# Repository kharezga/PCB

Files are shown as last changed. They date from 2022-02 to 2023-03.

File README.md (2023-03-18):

# My PCBs
This repository contains sereveral PCB board that I've design for use in the Formula Student racecar. In addition to PCB designs, the repository also includes 3D models of some of their housings.

## 🚨 Tractive System Active Light (TSAL) module 🚨
According to the Formula Student Rules 2022, the Tractive System Active Light (TSAL) is a safety feature that must be implemented in all electric vehicles participating in the competition. Whole project of the TSAL can be found in this repository, including PCB layout and scheme. 

### Overview
The TSAL must be based on the voltage level of the High Voltage (HV) battery or the voltage level of the motor controller, and it should indicate whether the tractive system is active or not.

The TSAL should be mounted on the rear of the vehicle and must be clearly visible from the rear of the vehicle during both day and night conditions. The light should be red or yellow and must flash at a frequency between 1Hz and 4Hz.

During normal operation, the TSAL should remain on steadily to indicate that the tractive system is active. When the vehicle is in an emergency or shutdown state, the TSAL should flash at a higher frequency between 4Hz and 10Hz to indicate that the tractive system is inactive.

## Ready-to-Run Sound and Autonomous System Status Indicators module
In this repository there is also a project containing a module for ready-to-run-sound and ASSI safety systems.

### 🔊 Ready-to-Run Sound 🔊
According to the Formula Student Rules 2022, Ready-to-Run Sound (RtRS) is a safety feature that must be implemented in all electric vehicles participating in the competition.

The purpose of the RtRS is to alert pedestrians and other drivers of the presence of an electric vehicle, which can be difficult to hear due to its quiet operation. The sound must be continuous, with a minimum sound pressure level of 55dB(A) and a maximum of 75dB(A) measured at a distance of 2 meters from the vehicle in all directions.

The RtRS must be activated when the vehicle is in Ready-to-Run mode, which means the vehicle is ready to move and all systems are operational. The sound should be automatically turned off when the vehicle is not in Ready-to-Run mode or is turned off.

### 🤖 Autonomous System Status Indicators 🤖
According to the Formula Student Rules 2022, the Autonomous System Status Indicators (ASSI) module is a safety feature that must be implemented in all autonomous vehicles participating in the competition.

The ASSI module is responsible for providing visual and audible feedback on the status of the autonomous system to the vehicle occupants, other drivers, and pedestrians. The module must be integrated into the vehicle's user interface or dashboard and should display the following information:

+ Autonomous System Status: The module must display the status of the autonomous system, indicating whether it is active or inactive.
+ System Health Status: The module must display the health status of the autonomous system, indicating whether the system is functioning correctly or not.
+ System State: The module must display the current state of the autonomous system, indicating whether the system is in calibration mode, initialization mode, or autonomous driving mode.

In addition to the visual feedback, the ASSI module must also provide audible feedback to alert the vehicle occupants and pedestrians of any critical issues related to the autonomous system. The audible feedback must be distinct and easily identifiable from any other sounds in the vehicle or surrounding environment.

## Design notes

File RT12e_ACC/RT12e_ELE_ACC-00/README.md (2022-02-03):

# RT12e_ELE_ACC_00
Projekt w kiCad'ie 5.1.8
Całość jest takze w pdf'ie w docs.

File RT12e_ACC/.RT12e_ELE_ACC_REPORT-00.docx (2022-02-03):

ELECTRONICS HARDWARE REPORT

Part | Rt12e_ELE_ACC
Department | Electronics
Owner | Bartosz Gwiazda
Owner’s e-mail | bartosz.gwiazda.pwrrt@gmail.com
Owner’s phone no. | 505613201
Season | 2020/21
Car | RT12e

# 1. Rules defining the part

# 2. Schedule

Beginning | End | Task
5.11 | 13.11 | Scheme creation
13.11 | 25.11 | Layout creation
11.12 | 18.12 | Fixes
4.01 | 12.01 | Case model

# 3. Description and ASSUmPTIONS of the part

Accelerometer, part used to read vehicle position and transfer it to can to future use.

# 4. Research

(previous team mainly)

- IAM-20680 datasheet
- STM32F042K6T datasheet
5. SIMULATIONS

(none)

# 6. PROTOTYPES

(in progress)

RT12e_ACC_00

- DESIGN RULES

(type of paths, paths width, min. size of vias – in the table, layers, etc.)

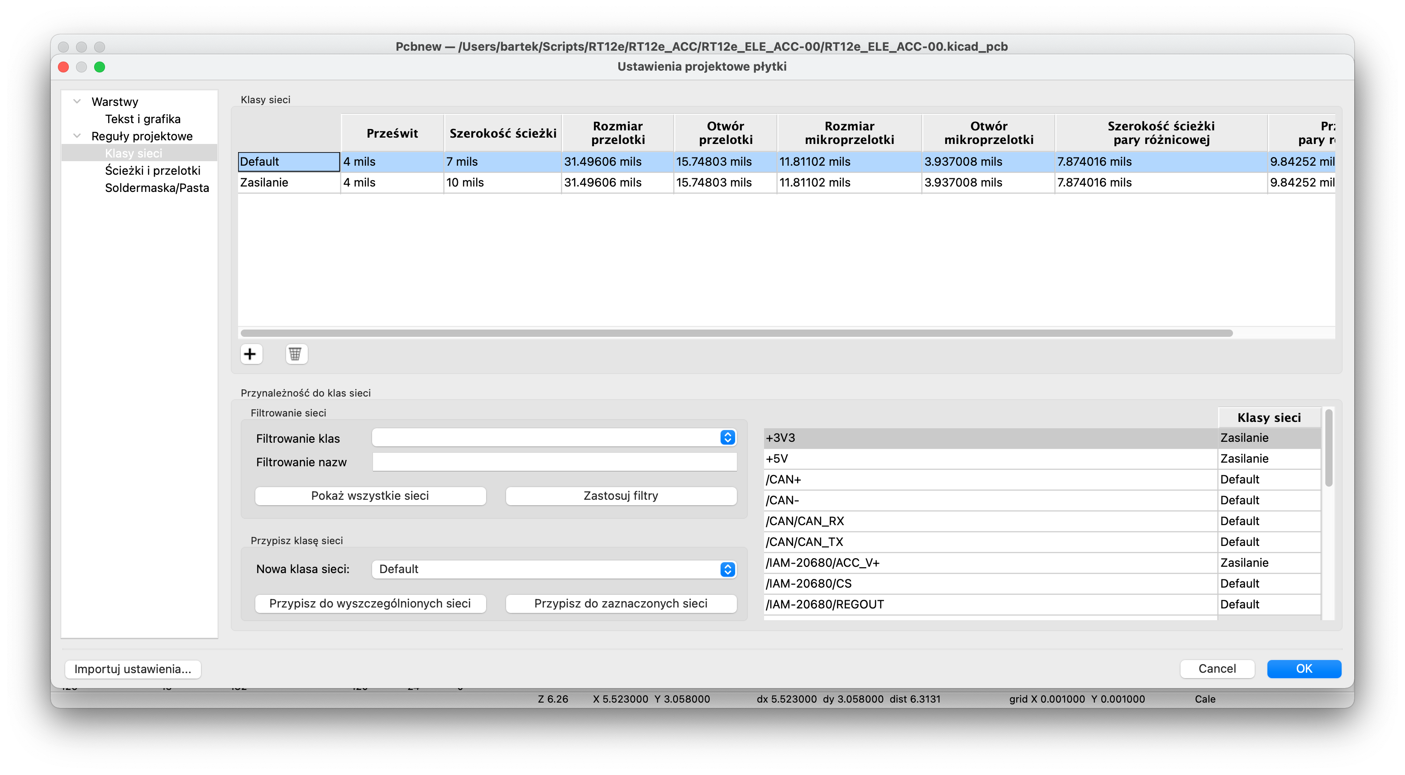
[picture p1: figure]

Figure 1. Paths classes

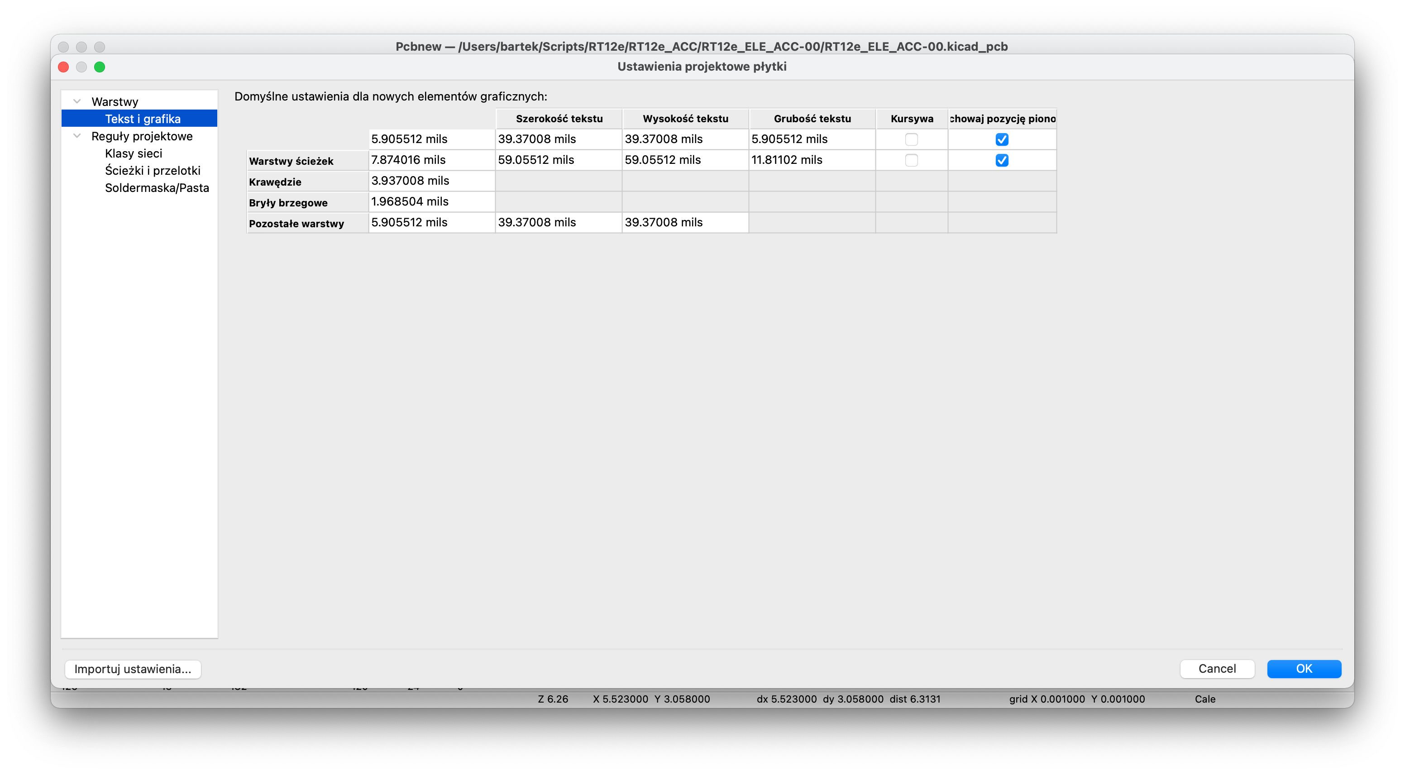
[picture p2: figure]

Figure 2. Text classes

- SCHEMA

(drawings, printed screens, photos – must have!. Includes each page of hierarchical sheet)

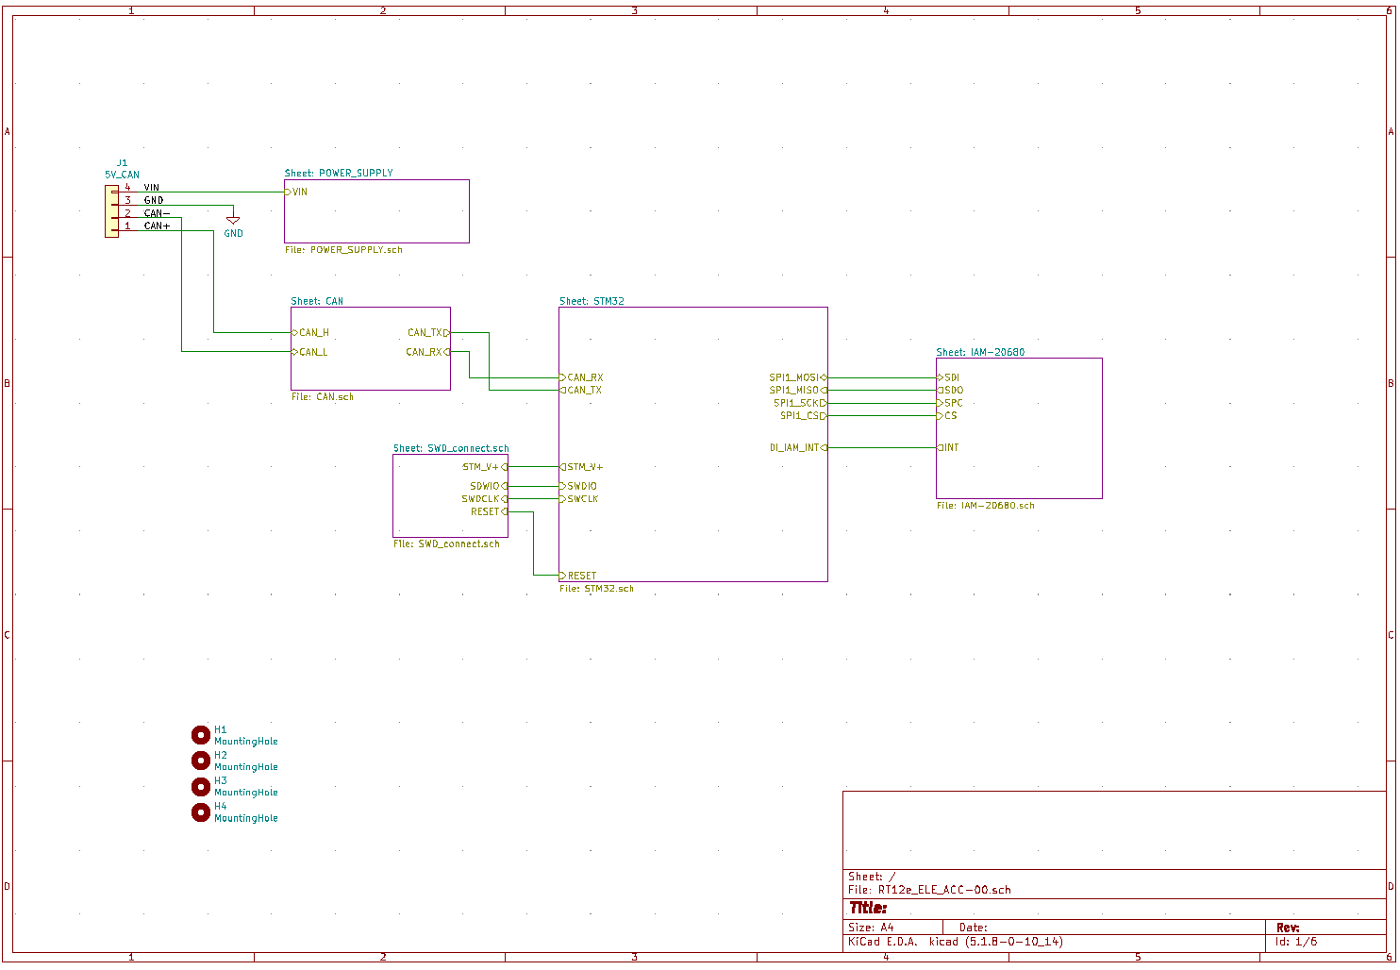
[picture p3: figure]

Figure 3. Main sheet of schema

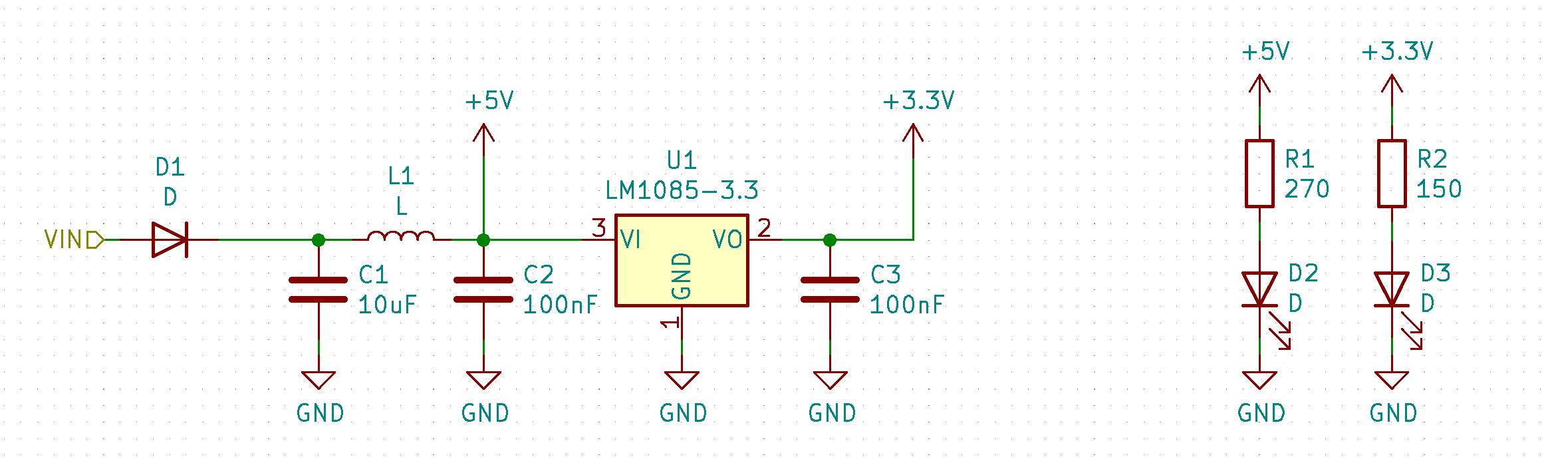
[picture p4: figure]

Figure 4. Power supply filer

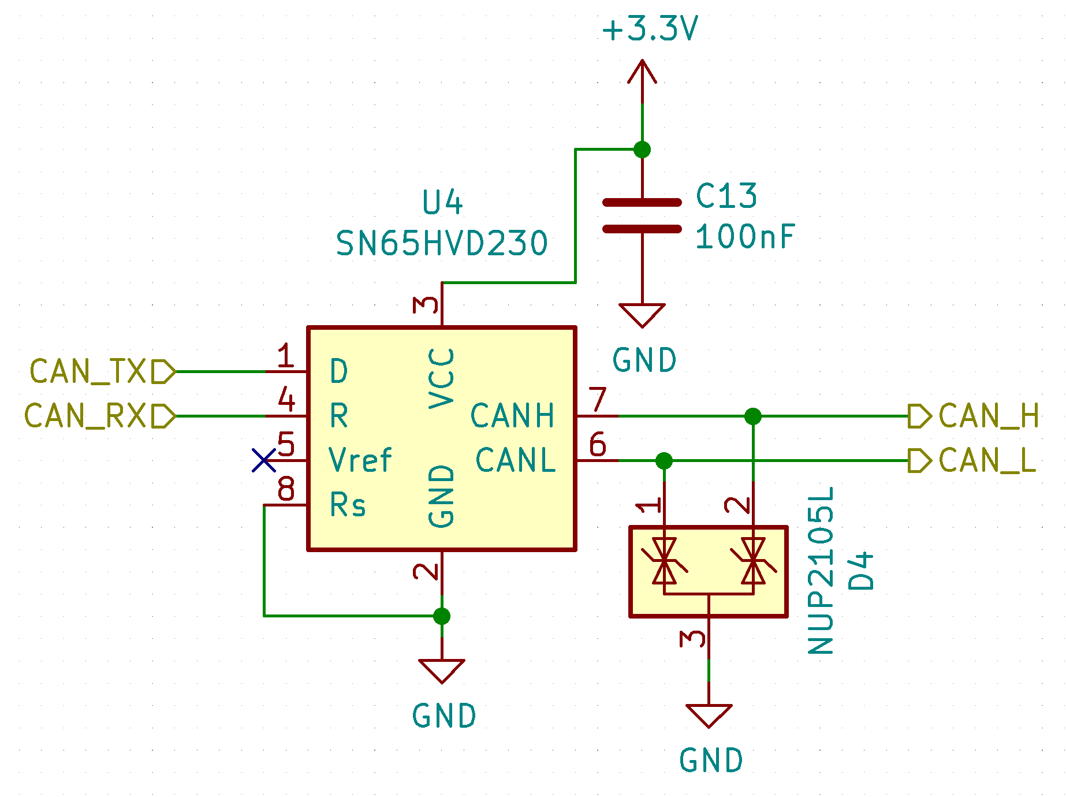
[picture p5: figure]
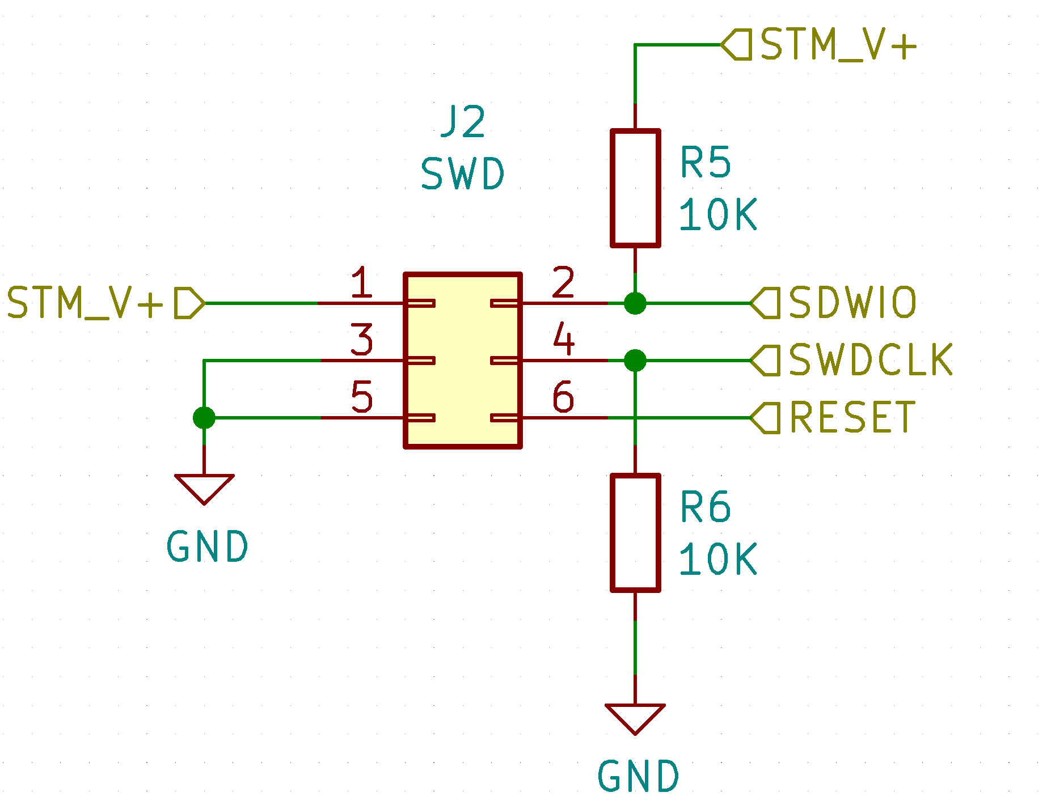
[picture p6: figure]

Figure 5. Can transceiver Figure 6. SDIO connector

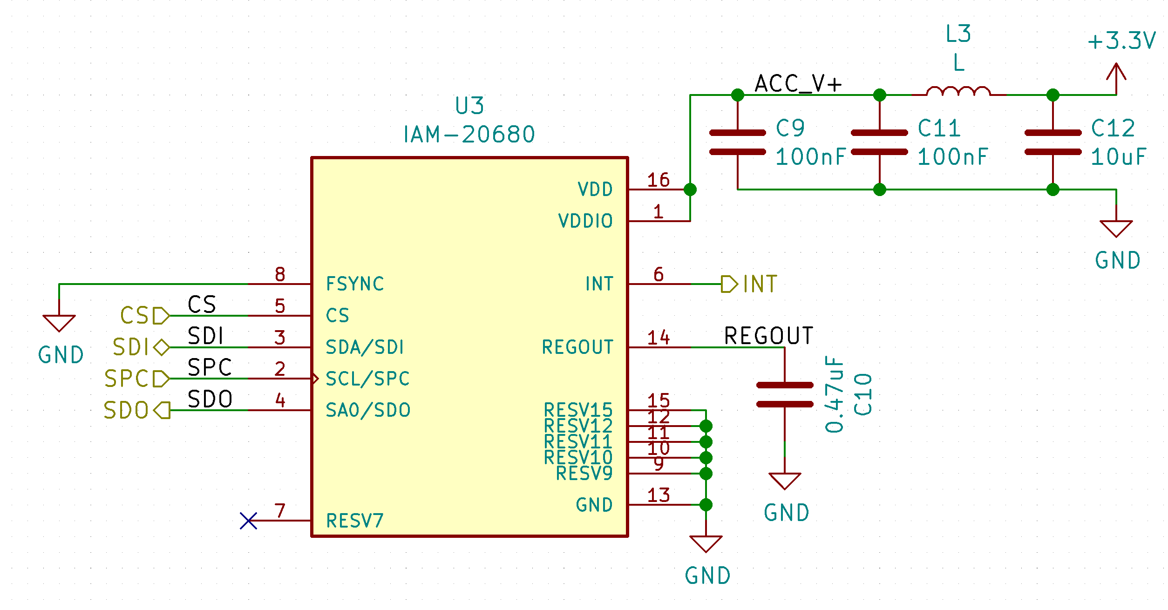
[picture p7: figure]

Figure 7. Accelerometer module

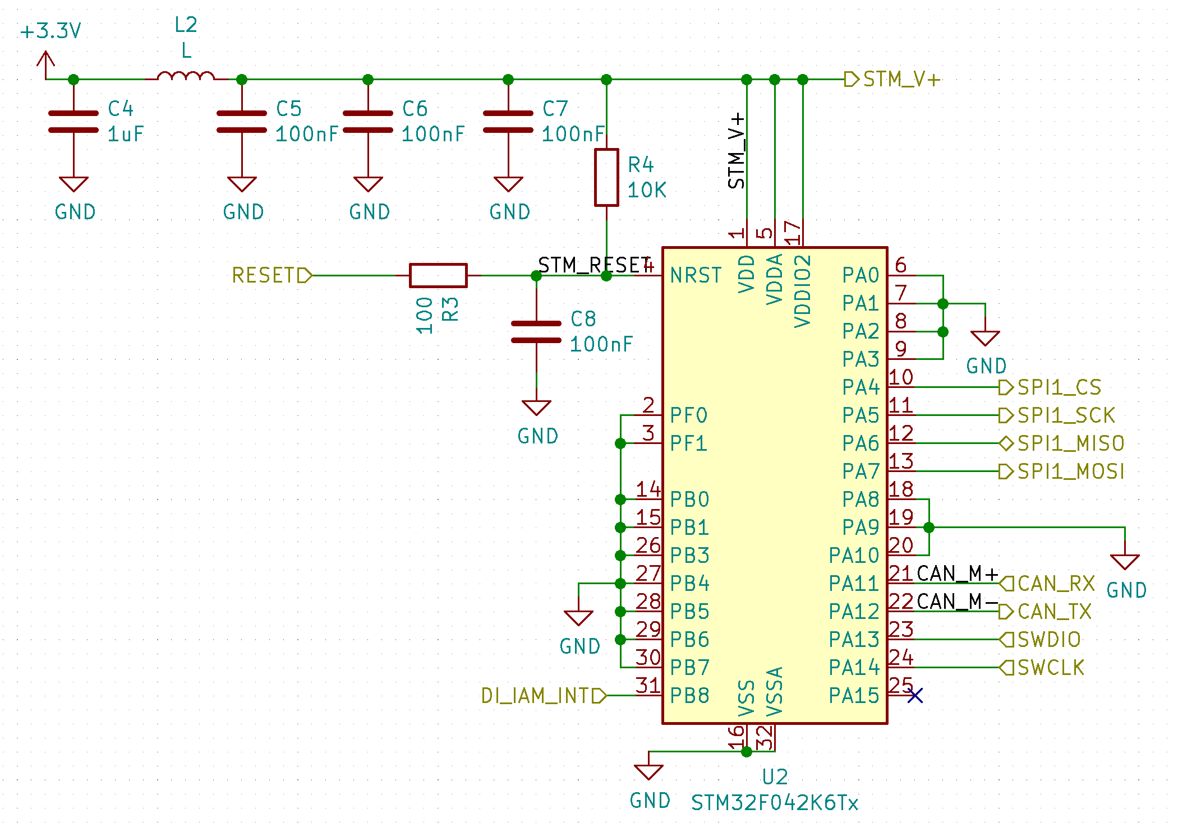
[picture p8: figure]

Figure 8. STM32 module

- LAYOUT PCB

(drawings, printed screens, photos – must have!. Includes each page of hierarchical sheet. If the PCB is large - many photos enlarged. )

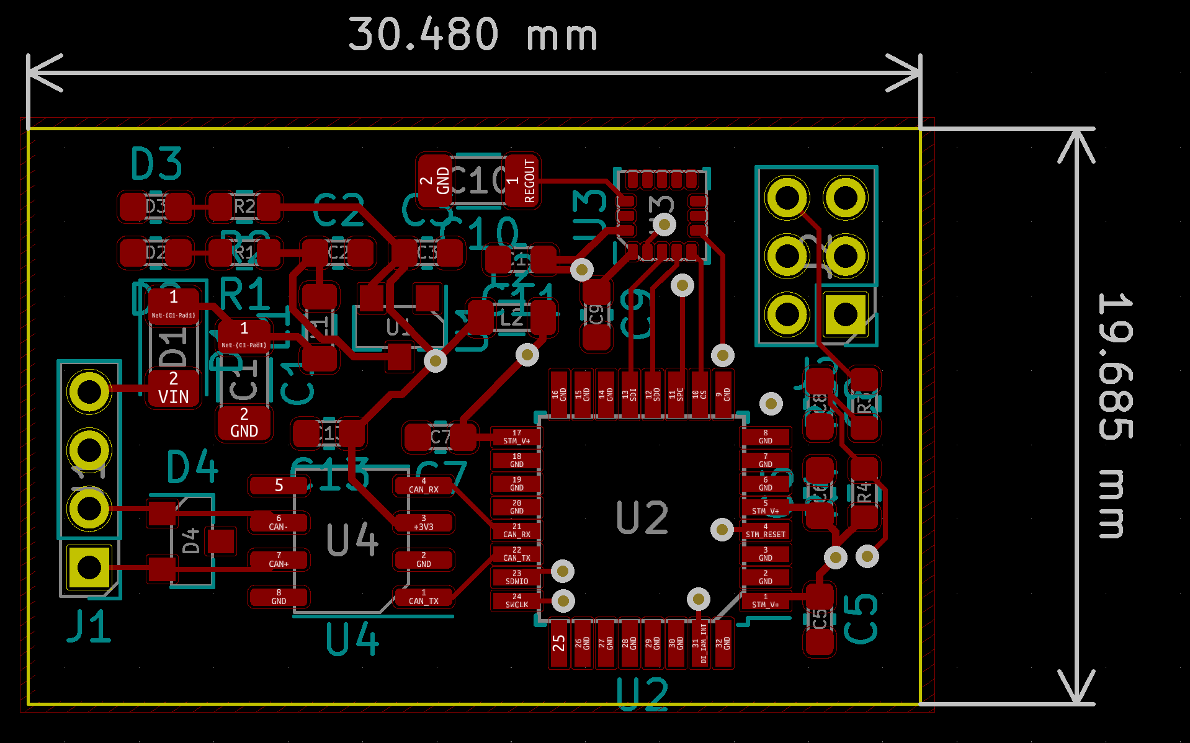
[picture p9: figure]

Figure 9. Top layer layout

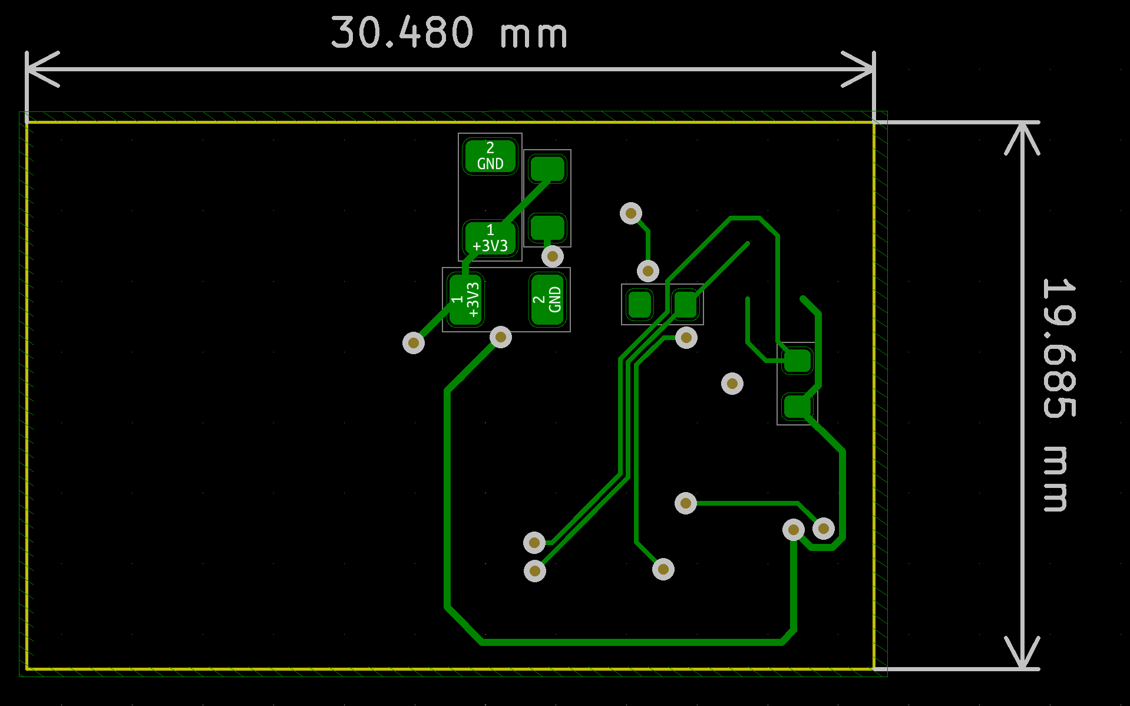
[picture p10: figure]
Obraz zawierający tekst, sprzęt elektroniczny Opis wygenerowany automatycznie

Figure 10. Bottom layer layout

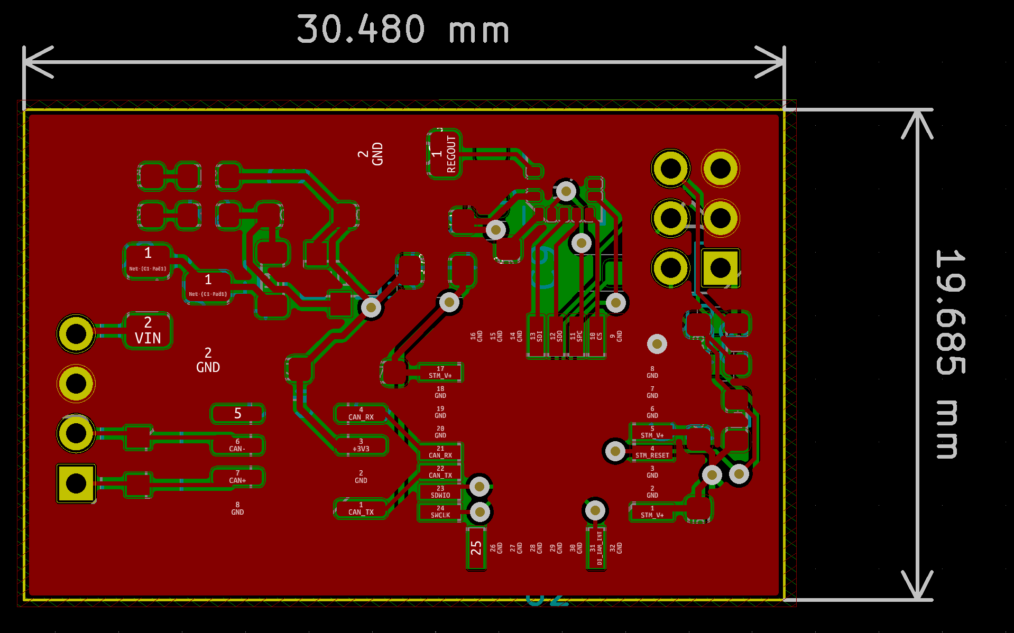
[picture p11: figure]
Obraz zawierający tekst, sprzęt elektroniczny Opis wygenerowany automatycznie

Figure 11. Top GND

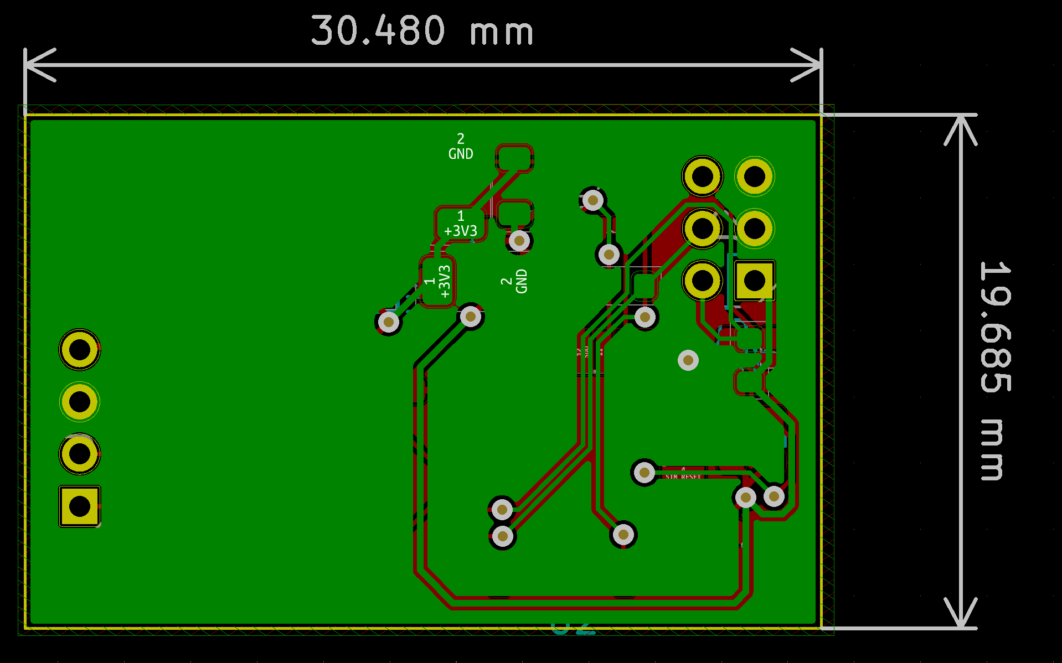
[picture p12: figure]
Obraz zawierający tekst, sprzęt elektroniczny, obwód Opis wygenerowany automatycznie

Figure 12. Bottom GND

# 7. FInal MODEL

- DESIGN RULES

(type of paths, paths width, min. size of vias – in the table, layers, etc.)

- SCHEMA

(drawings, printed screens, photos – must have!. Includes each page of hierarchical sheet)

- LAYOUT PCB

(drawings, printed screens, photos – must have!. If the PCB is large - many photos enlarged.)

8. Comparison of different versions

(what was changed – why?, why not?, made decisions between releases, which components was changed/removed? etc…)

9. 3D MODEL AND PLACEMENT ON THE CAR

(where and why the part is located, pictures, screens, drawings of assemblies, assumptions for location on the car )

There are two types of use this device in car. First, main in center of car, under steering rode to measure car vibrations and position. Second type is on all four wheels steering to measure vibrations and behavior of dumpers.

10. TESTS

(type of the test[current measurment, voltage measurment, switching time etc.], what is needed to do the tests, proces of the tests, PICTURES!)

11. IDEAS FOR THE NEXT SEASON

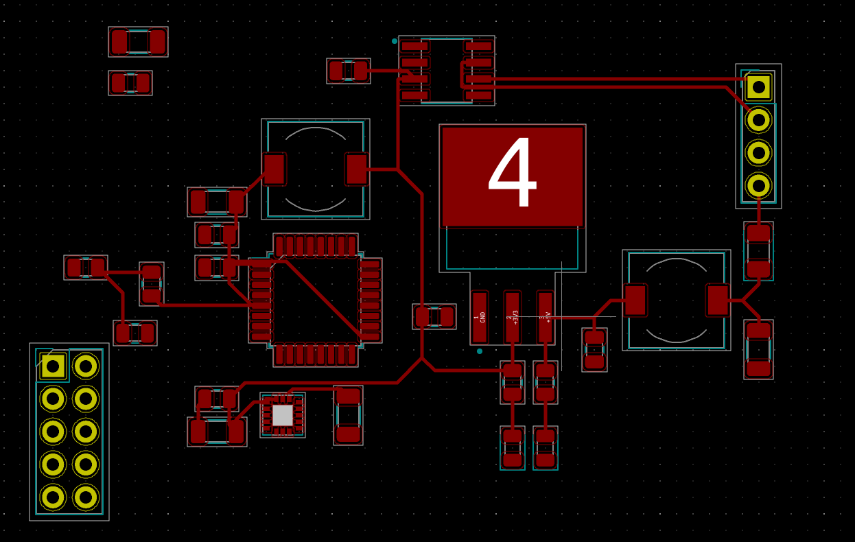
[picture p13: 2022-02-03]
RT12e_ACC/RT12e_ELE_ACC-00/Docs/Screenshot of circuit.png

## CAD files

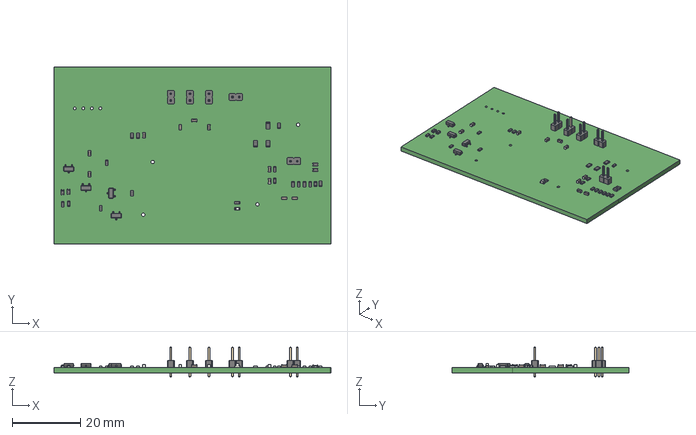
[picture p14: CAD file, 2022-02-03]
RT12e_TSAL/RT12e_ELE_TSAL-00/STEP/RT12_TSAL_00_3D_MODEL.step
81.3 x 52.1 x 8.80 mm

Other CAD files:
RT12e_ACC/NX_CASE_MAIN/RT12e.prt
RT12e_ACC/NX_CASE_MAIN/RT12e_CHS.prt
RT12e_ACC/NX_CASE_MAIN/RT12e_ELE_ACC_MAIN-00.prt
RT12e_ACC/NX_CASE_MAIN/RT12e_ELE_ACC_MAIN_TOP-00.prt
RT12e_ACC/NX_CASE_MAIN/RT12e_ELE_ACC_PCB-00.prt
RT12e_ACC/NX_CASE_MAIN/RT12e_SUS.prt
RT12e_ACC/NX_CASE_MAIN/RT12e_SUS_Steering_Housing.prt
RT12e_ACC/NX_CASE_MAIN/RT12e_SUS_Steering_Mount.prt
RT12e_ACC/NX_CASE_MAIN/RT12e_SUS_Steering_System.prt
RT12e_ACC/NX_CASE_UPRIGHT/RT12e_ELE_ACC_PCB-00.prt
RT12e_ACC/NX_CASE_UPRIGHT/RT12e_ELE_ACC_UPRIGHT-00.prt
RT12e_ACC/NX_CASE_UPRIGHT/RT12e_ELE_ACC_UPRIGHT_BOX-00.prt
RT12e_ACC/NX_CASE_UPRIGHT/RT12e_ELE_ACC_UPRIGHT_TOP-00.prt
RT12e_ACC/NX_CASE_UPRIGHT/RT12e_SUS_Wheel_Assembly_Upright_Front_Right.prt
RT12e_ACC/NX_CASE_UPRIGHT/Wheel_ACC_assembly.prt
RT12e_TSAL/RT12e_ELE_TSAL-00/STEP/COMPOUND.prt
RT12e_TSAL/RT12e_ELE_TSAL-00/STEP/C_0603_1608Metric.prt
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

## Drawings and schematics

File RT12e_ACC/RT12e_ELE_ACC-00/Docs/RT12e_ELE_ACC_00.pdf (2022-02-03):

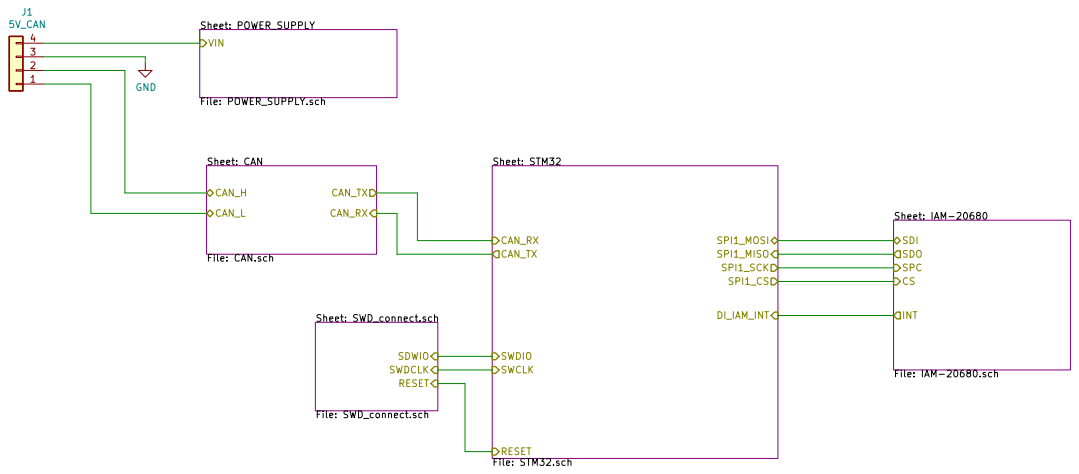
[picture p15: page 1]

SWDCLK RESET Sheet: CAN

Sheet: STM32 File: STM32.sch SWCLK

Sheet: SWD_connect.sch File: SWD_connect.sch SDWIO

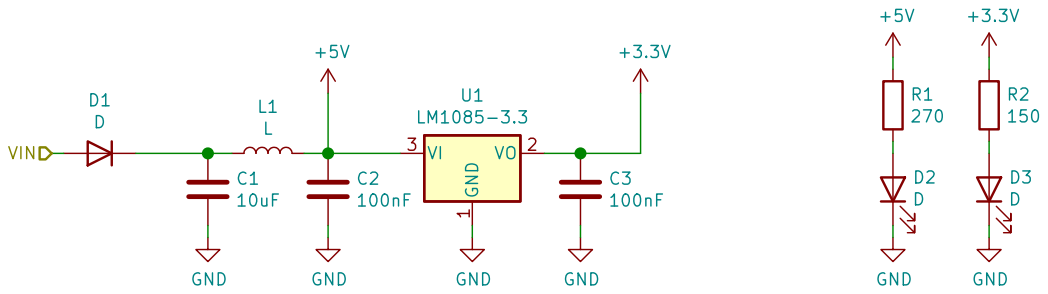
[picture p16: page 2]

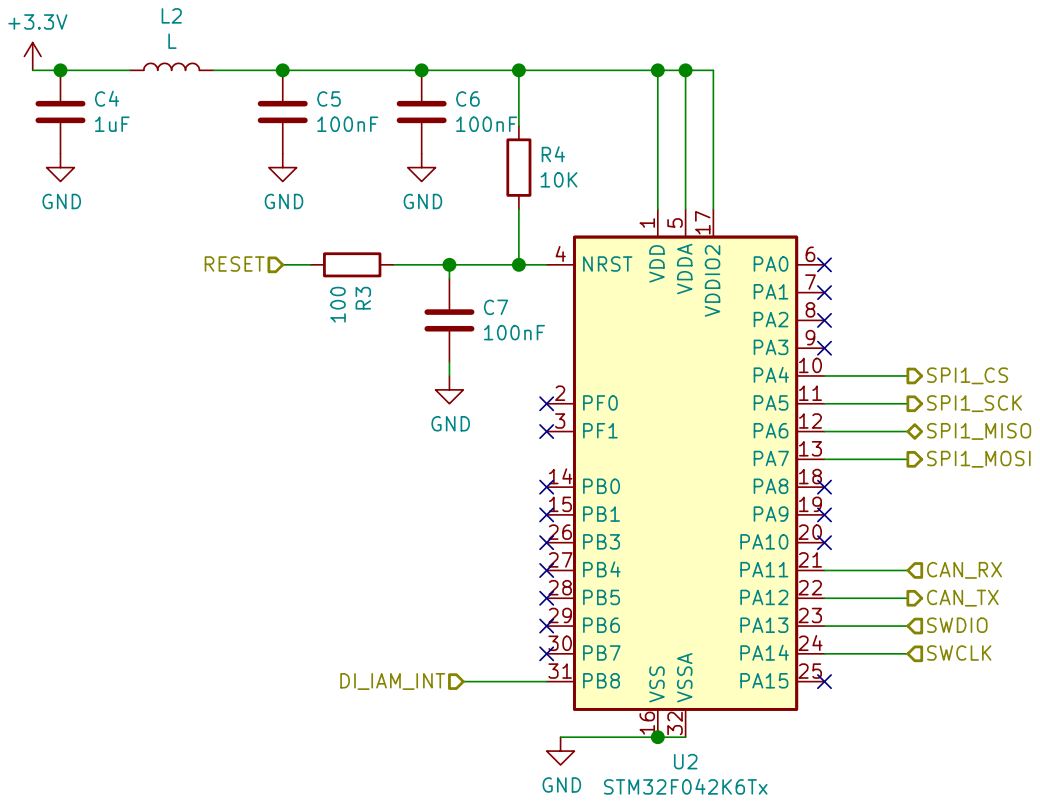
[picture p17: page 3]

1 PA4 10 PA5 11 PA6 12 PA7 13 PB0 14 PB1 15 VSS 16 VDDIO2 17 PA8 18 PA9 19 PF0 2 PA10 20 PA11 21 PA12 22 PA13 23 PA14 24 PA15 25 PB3 26 PB4 27 PB5 28 PB6 29 PF1 3 PB7 30 PB8 31 VSSA 32 NRST 4 VDDA

5 PA0 6 PA1 7 PA2 8 PA3 9 U2 STM32F042K6Tx
Id: 3/6 Title: File: STM32.sch Sheet: /STM32/ VDD

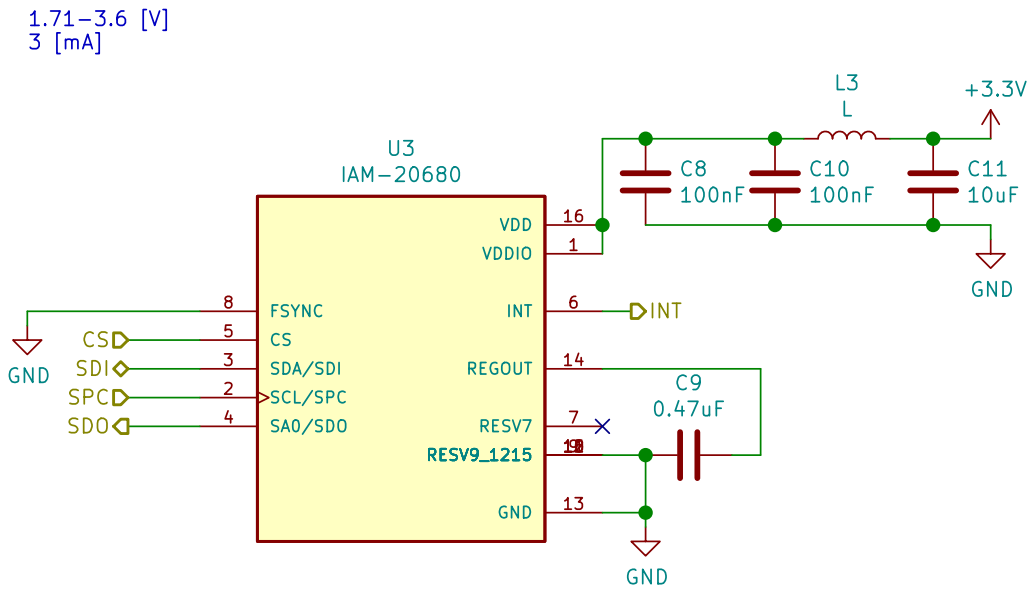
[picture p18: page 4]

Id: 4/6 Title: File: IAM-20680.sch Sheet: /IAM-20680/

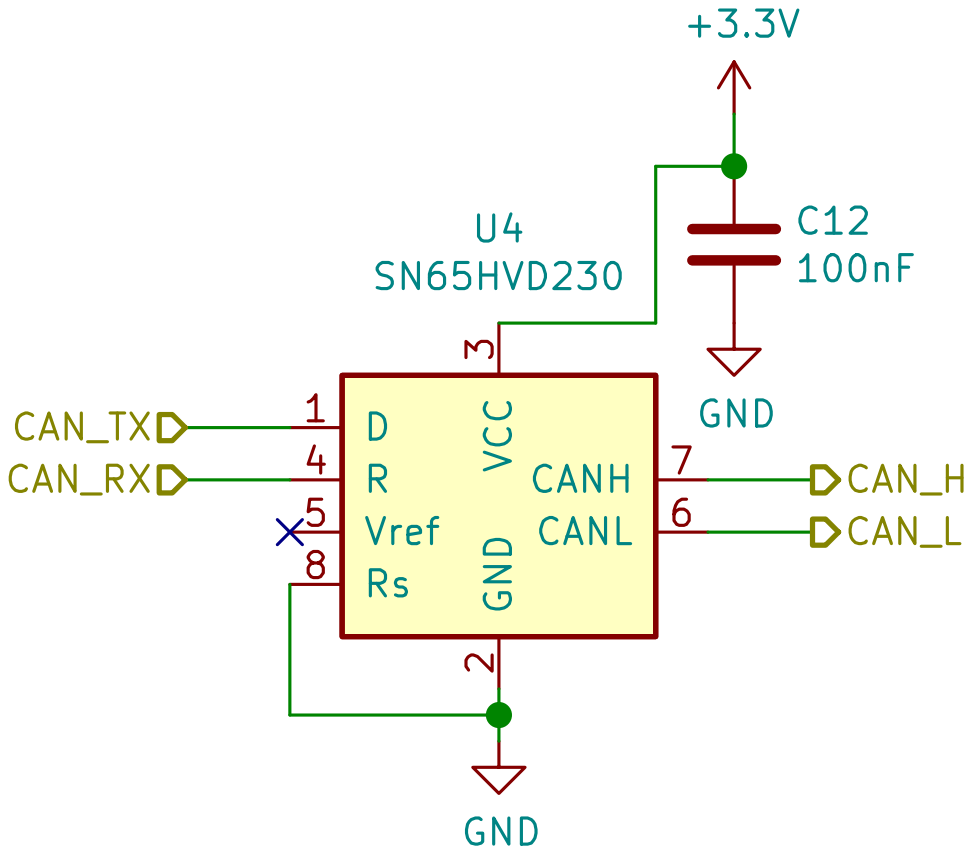
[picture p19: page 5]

Id: 5/6 Title: File: CAN.sch Sheet: /CAN/

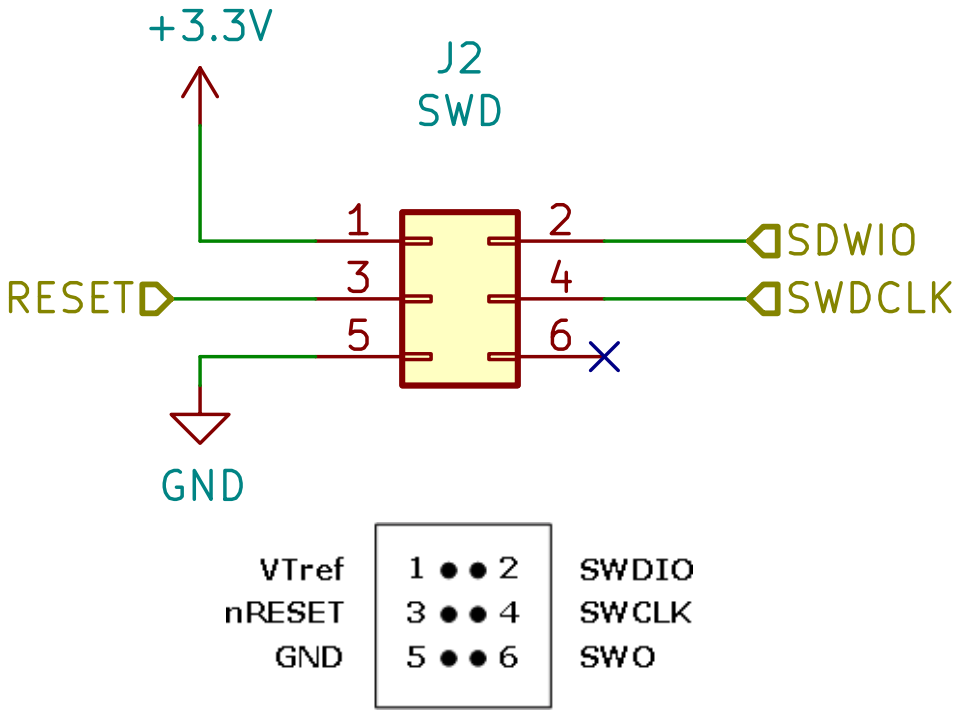
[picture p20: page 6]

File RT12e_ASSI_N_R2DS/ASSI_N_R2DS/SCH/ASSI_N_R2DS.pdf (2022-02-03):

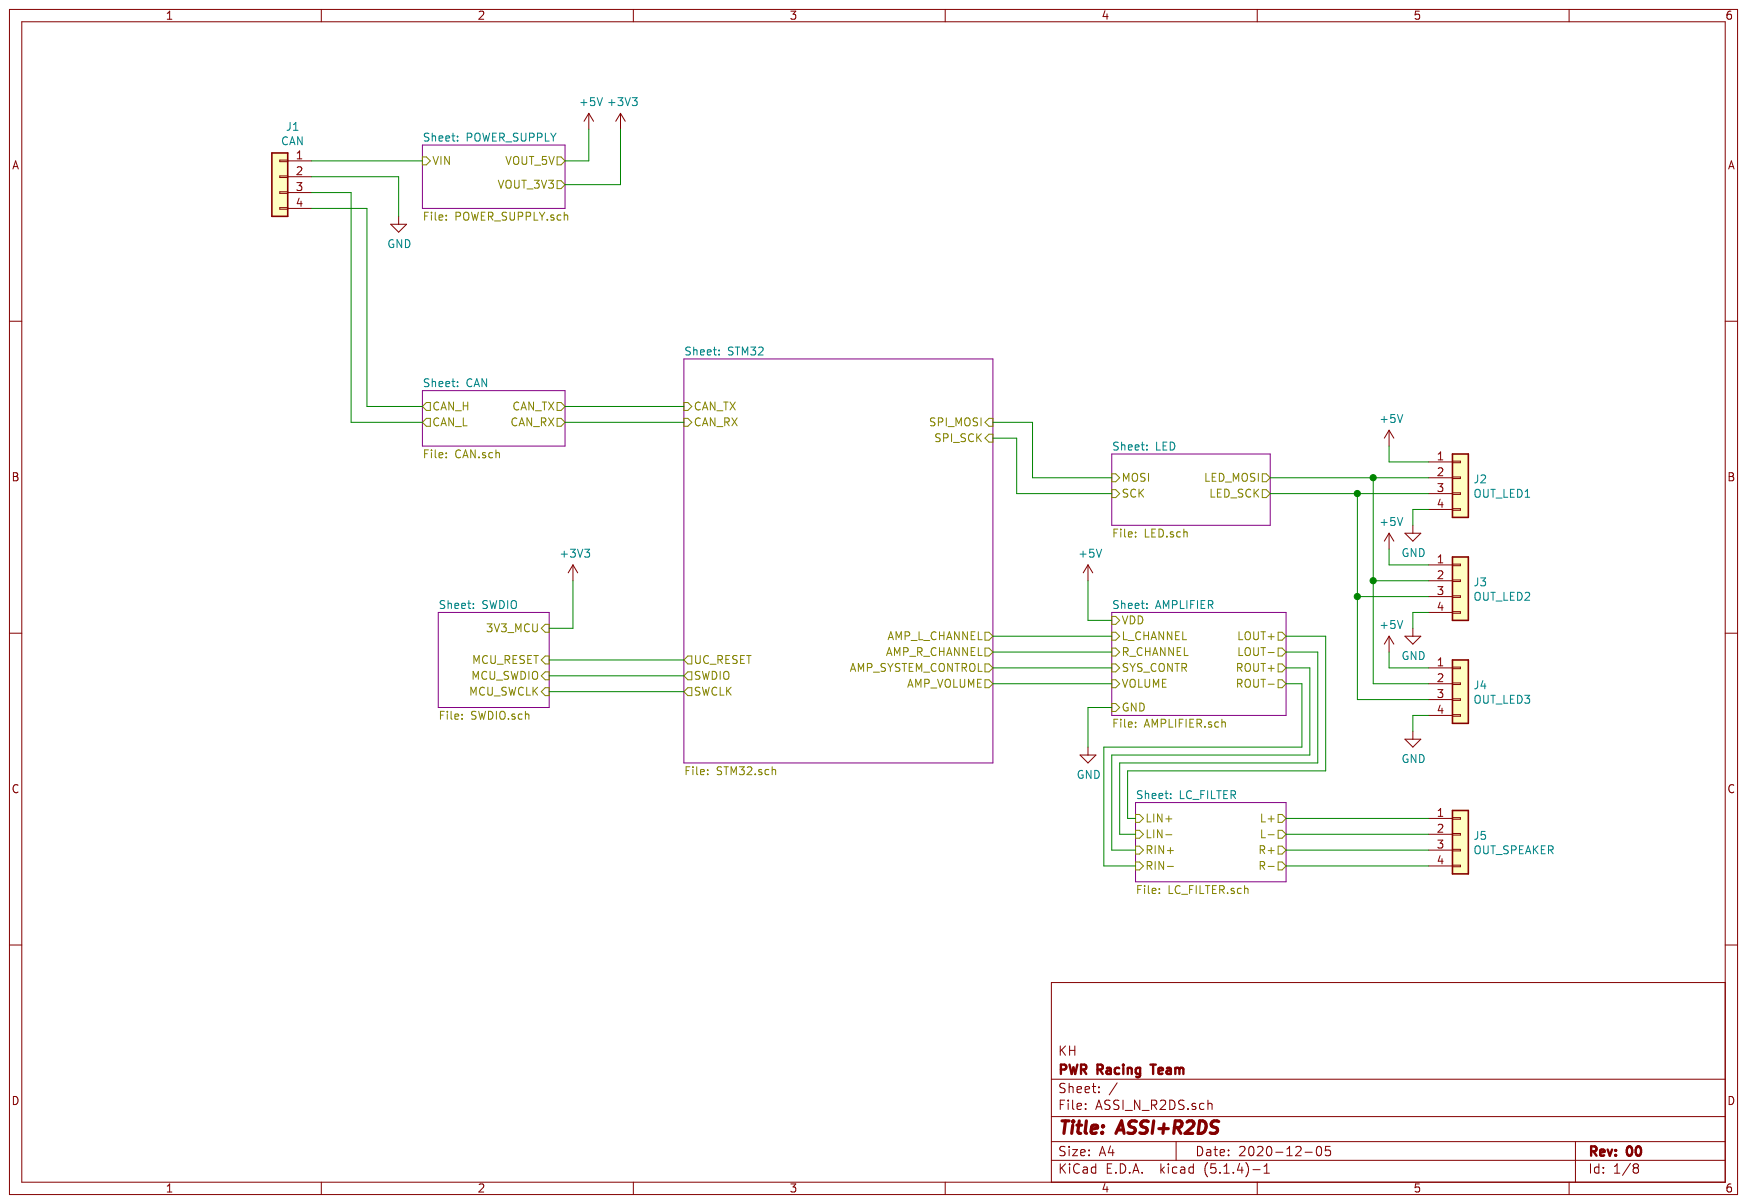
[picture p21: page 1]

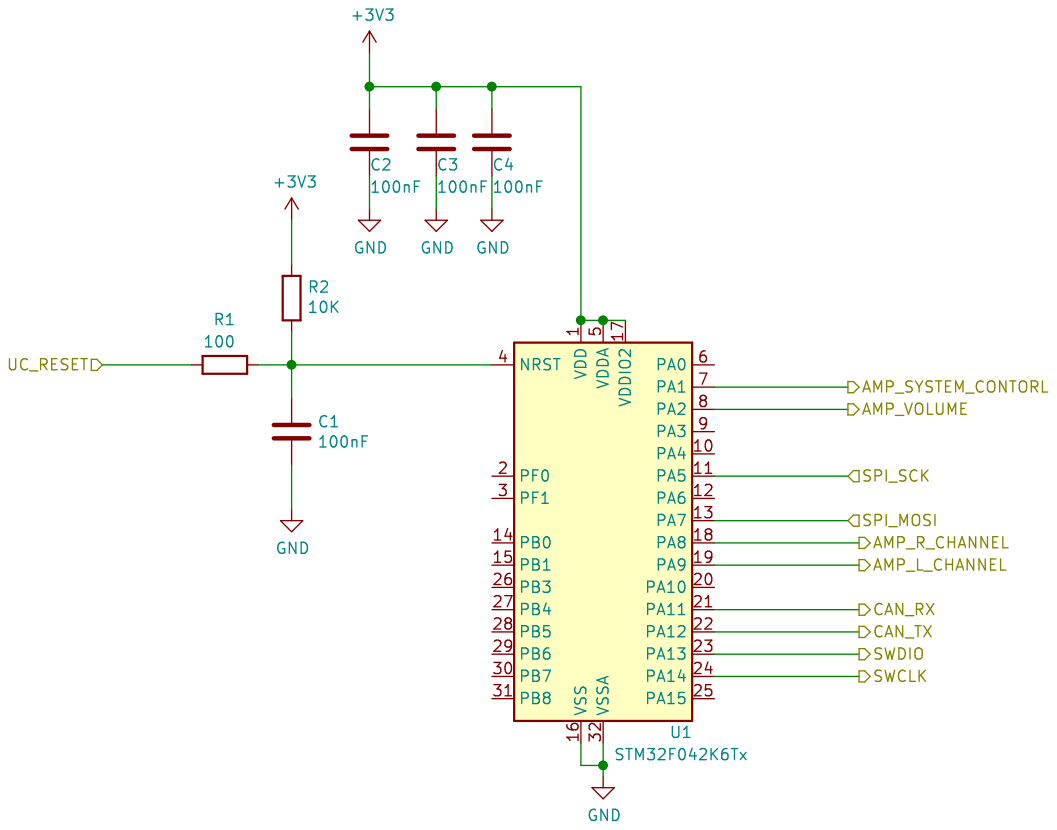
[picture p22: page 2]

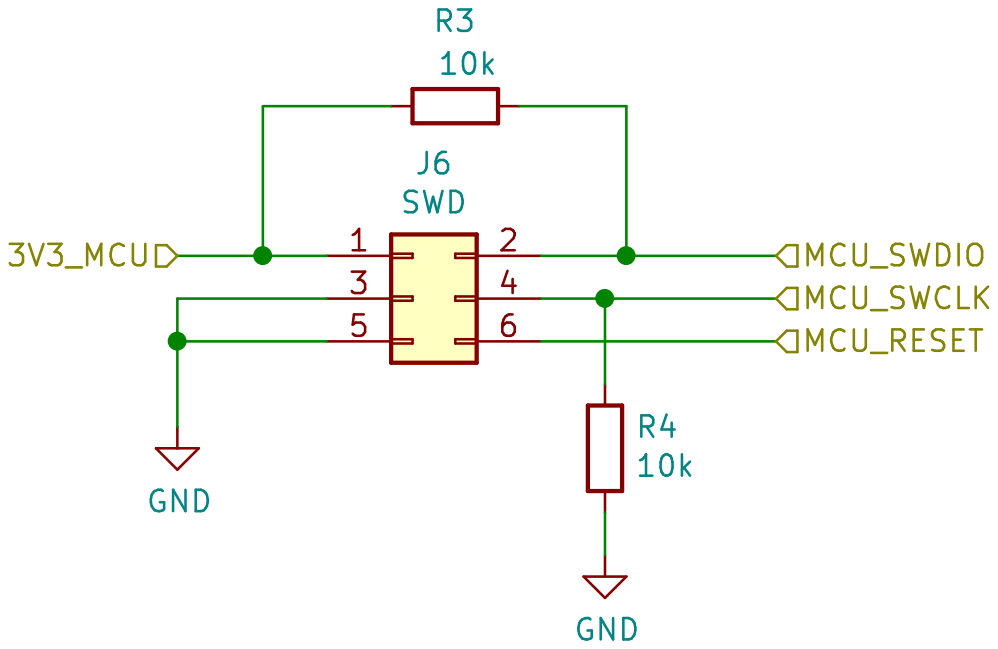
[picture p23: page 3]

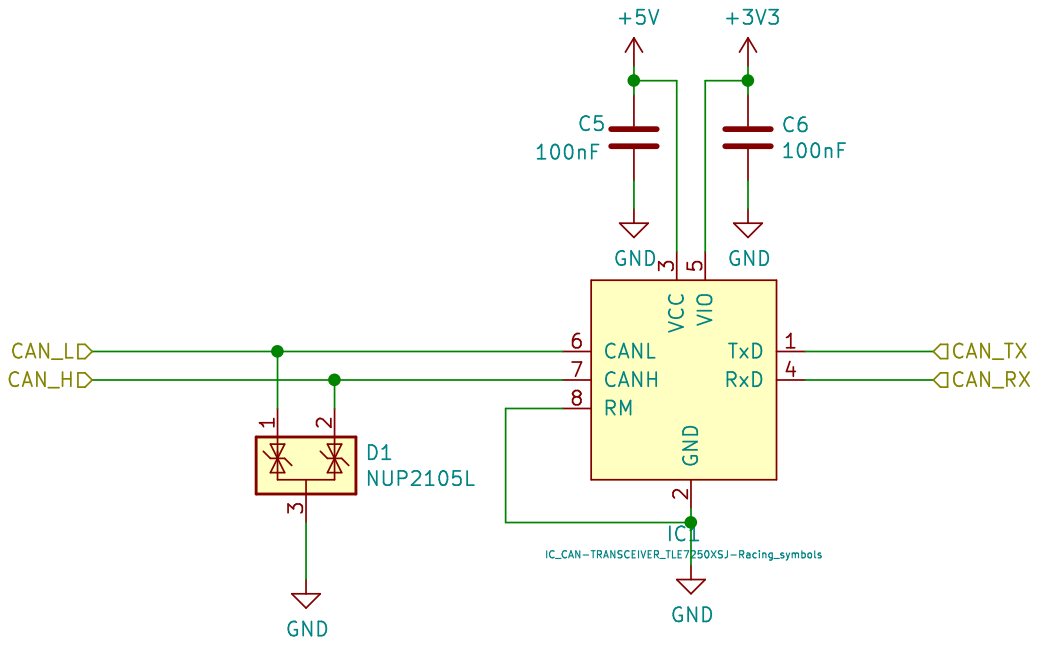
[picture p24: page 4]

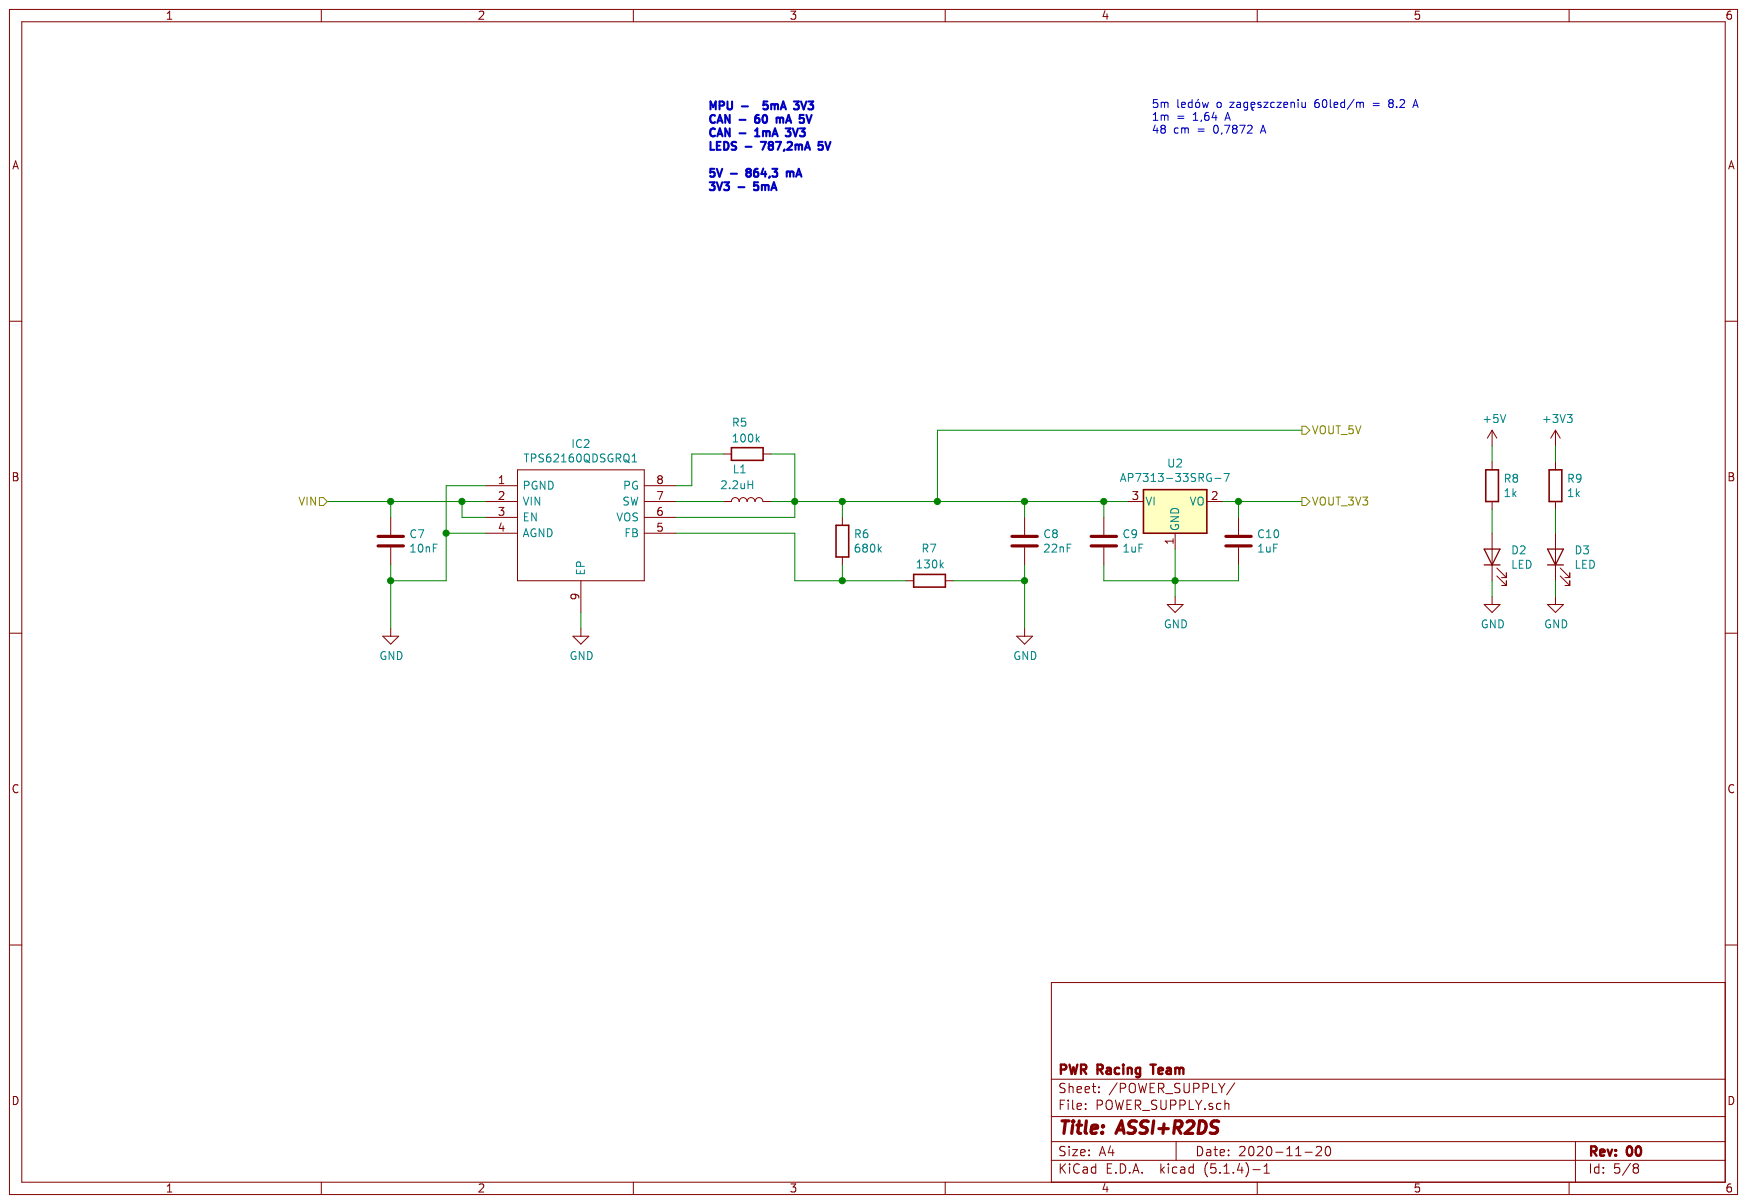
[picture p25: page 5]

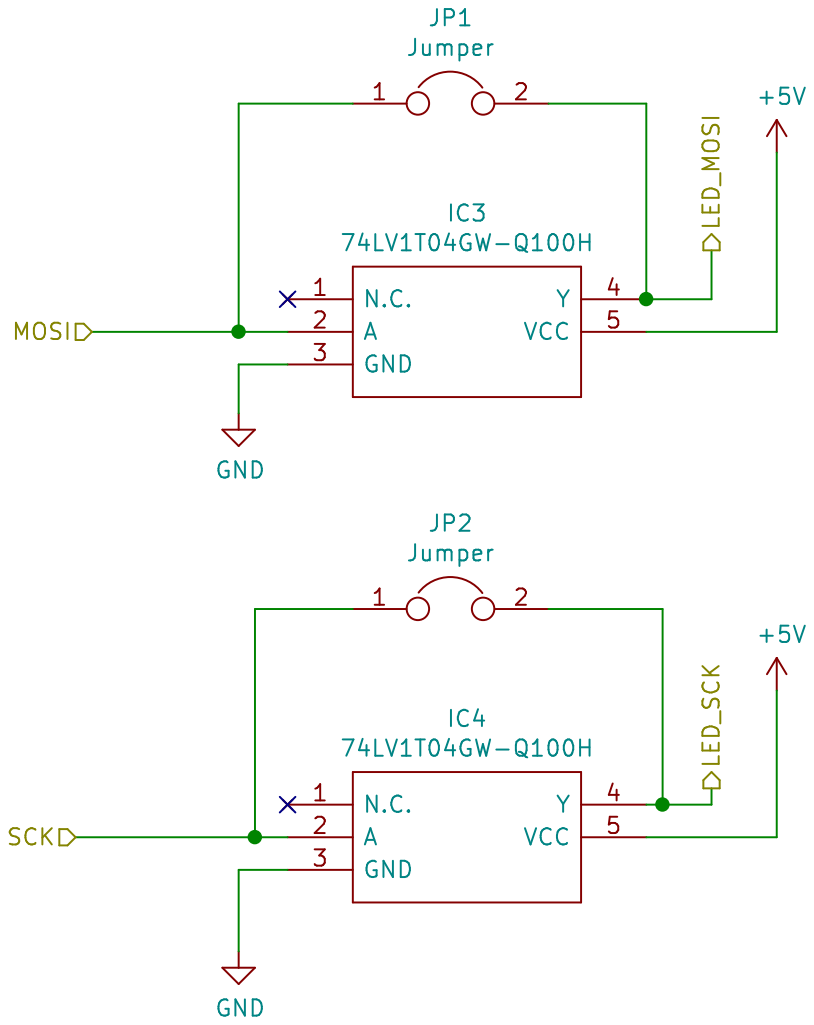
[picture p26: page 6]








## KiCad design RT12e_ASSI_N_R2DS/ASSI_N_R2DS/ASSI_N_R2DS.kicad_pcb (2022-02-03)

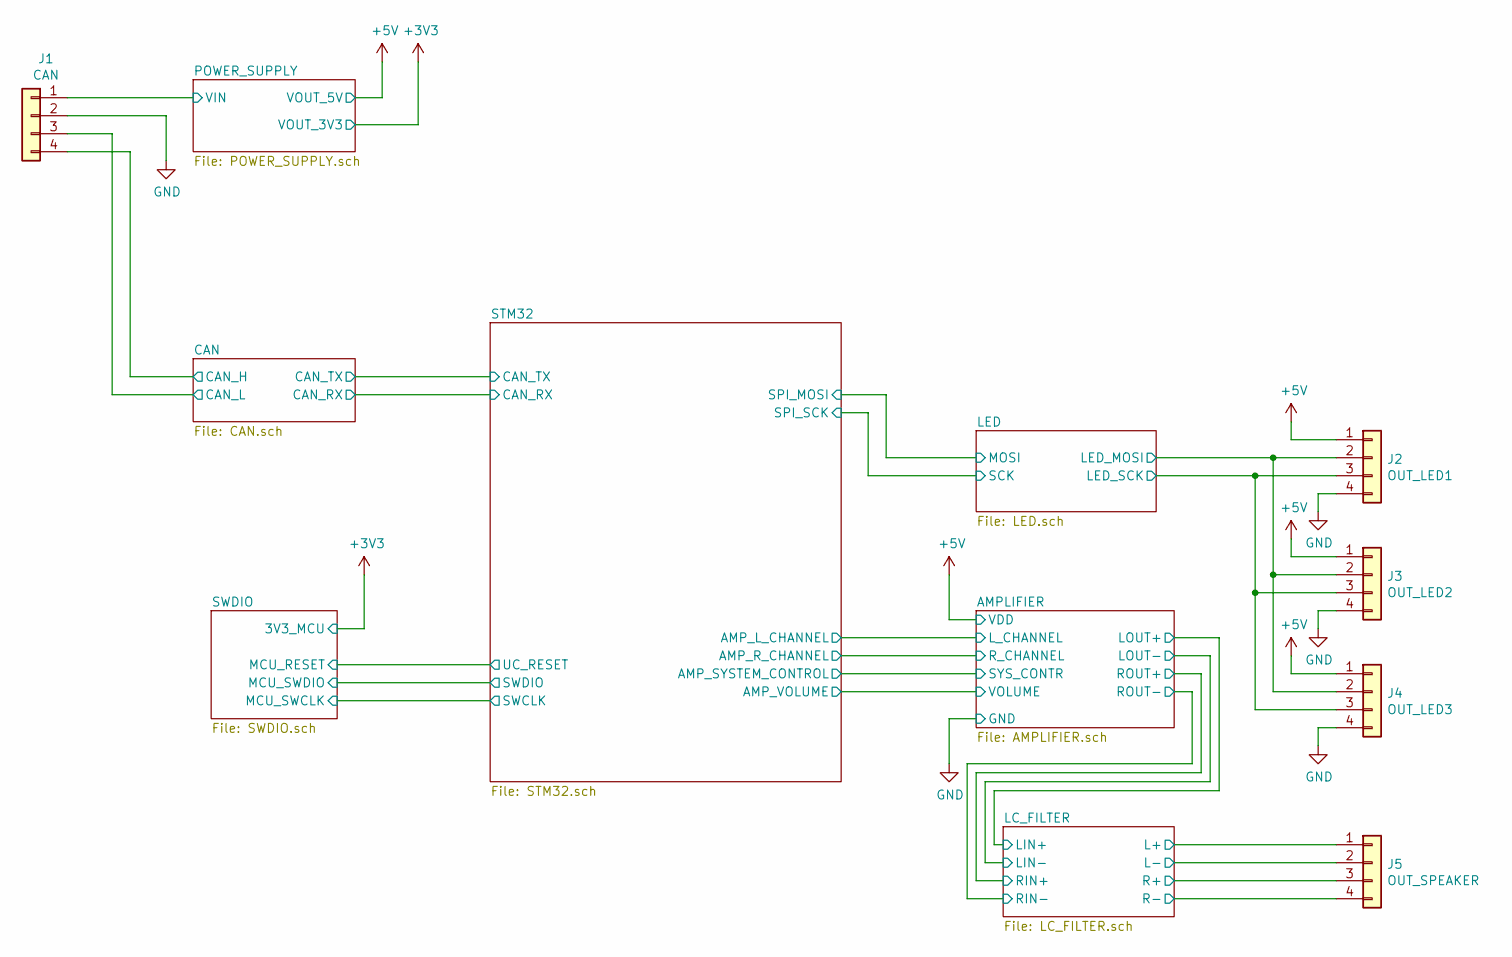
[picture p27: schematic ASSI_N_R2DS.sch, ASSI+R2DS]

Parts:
J1: CAN; JST_JWPF_B04B-JWPF-SK-R_1x04_P2.00mm_Vertical
J2: OUT_LED1; JST_JWPF_B04B-JWPF-SK-R_1x04_P2.00mm_Vertical
J3: OUT_LED2; JST_JWPF_B04B-JWPF-SK-R_1x04_P2.00mm_Vertical
J4: OUT_LED3; JST_JWPF_B04B-JWPF-SK-R_1x04_P2.00mm_Vertical
J5: OUT_SPEAKER; JST_JWPF_B04B-JWPF-SK-R_1x04_P2.00mm_Vertical

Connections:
+5V: J2.1, J3.1, J4.1; also elsewhere on the board
/CAN/CAN_H: J1.4; also elsewhere on the board
/CAN/CAN_L: J1.3; also elsewhere on the board
/LC_FILTER/L+: J5.1; also elsewhere on the board
/LC_FILTER/L-: J5.2; also elsewhere on the board
/LC_FILTER/R+: J5.3; also elsewhere on the board
/LC_FILTER/R-: J5.4; also elsewhere on the board
/LED/LED_MOSI: J2.2, J3.2, J4.2; also elsewhere on the board
/LED/LED_SCK: J2.3, J3.3, J4.3; also elsewhere on the board
/POWER_SUPPLY/VIN: J1.1; also elsewhere on the board
GND: J1.2, J2.4, J3.4, J4.4; also elsewhere on the board

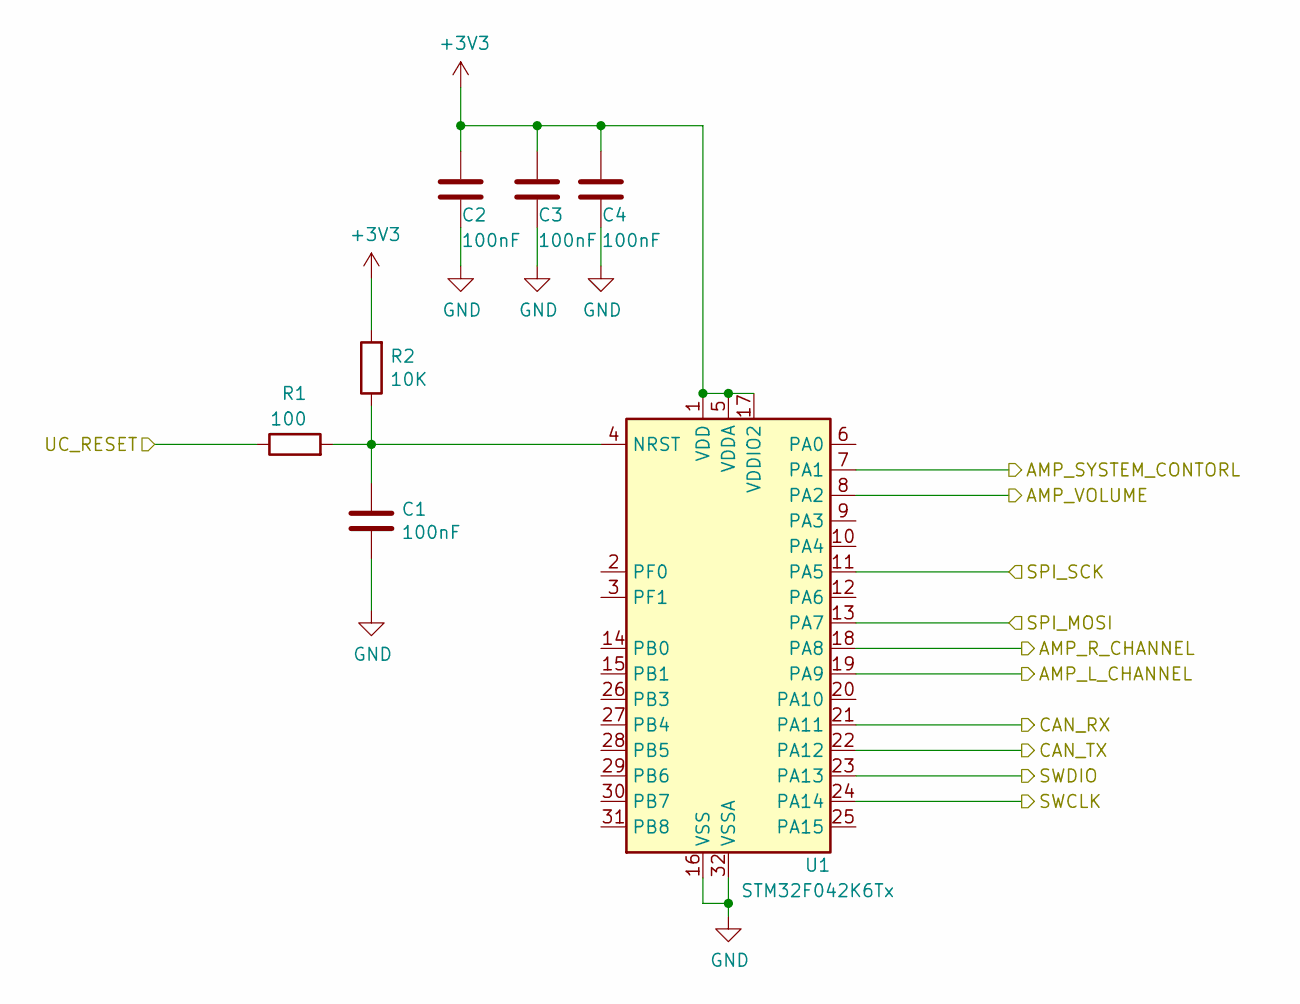
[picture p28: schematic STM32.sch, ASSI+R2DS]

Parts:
C1, C2, C3, C4: 100nF; C_0603_1608Metric
R1: 100; R_0603_1608Metric
R2: 10K; R_0603_1608Metric
U1: STM32F042K6Tx; LQFP-32_7x7mm_P0.8mm

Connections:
+3V3: C2.1, C3.1, C4.1, R2.2, U1.1 (VDD), U1.5 (VDDA), U1.17 (VDDIO2); also elsewhere on the board
/CAN/CAN_RX: U1.21 (PA11); also elsewhere on the board
/CAN/CAN_TX: U1.22 (PA12); also elsewhere on the board
/LED/MOSI: U1.13 (PA7); also elsewhere on the board
/LED/SCK: U1.11 (PA5); also elsewhere on the board
/STM32/AMP_L_CHANNEL: U1.19 (PA9); also elsewhere on the board
/STM32/AMP_R_CHANNEL: U1.18 (PA8); also elsewhere on the board
/STM32/AMP_SYSTEM_CONTORL: U1.7 (PA1)
/STM32/AMP_VOLUME: U1.8 (PA2); also elsewhere on the board
/SWDIO/MCU_RESET: R1.1; also elsewhere on the board
/SWDIO/MCU_SWCLK: U1.24 (PA14); also elsewhere on the board
/SWDIO/MCU_SWDIO: U1.23 (PA13); also elsewhere on the board
GND: C1.2, C2.2, C3.2, C4.2, U1.16 (VSS), U1.32 (VSSA); also elsewhere on the board
unnamed: C1.1, R1.2, R2.1, U1.4 (NRST)

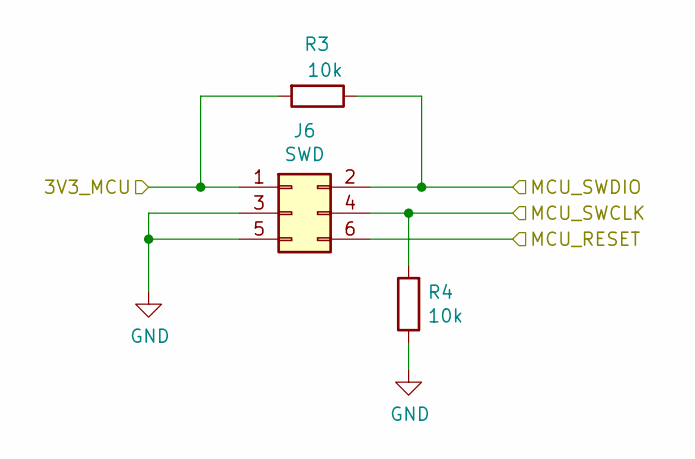
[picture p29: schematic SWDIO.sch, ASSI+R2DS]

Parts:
J6: SWD; PinSocket_2x03_P2.00mm_Vertical
R3, R4: 10k; R_0603_1608Metric

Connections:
+3V3: J6.1, R3.2; also elsewhere on the board
/SWDIO/MCU_RESET: J6.6; also elsewhere on the board
/SWDIO/MCU_SWCLK: J6.4, R4.2; also elsewhere on the board
/SWDIO/MCU_SWDIO: J6.2, R3.1; also elsewhere on the board
GND: J6.3, J6.5, R4.1; also elsewhere on the board

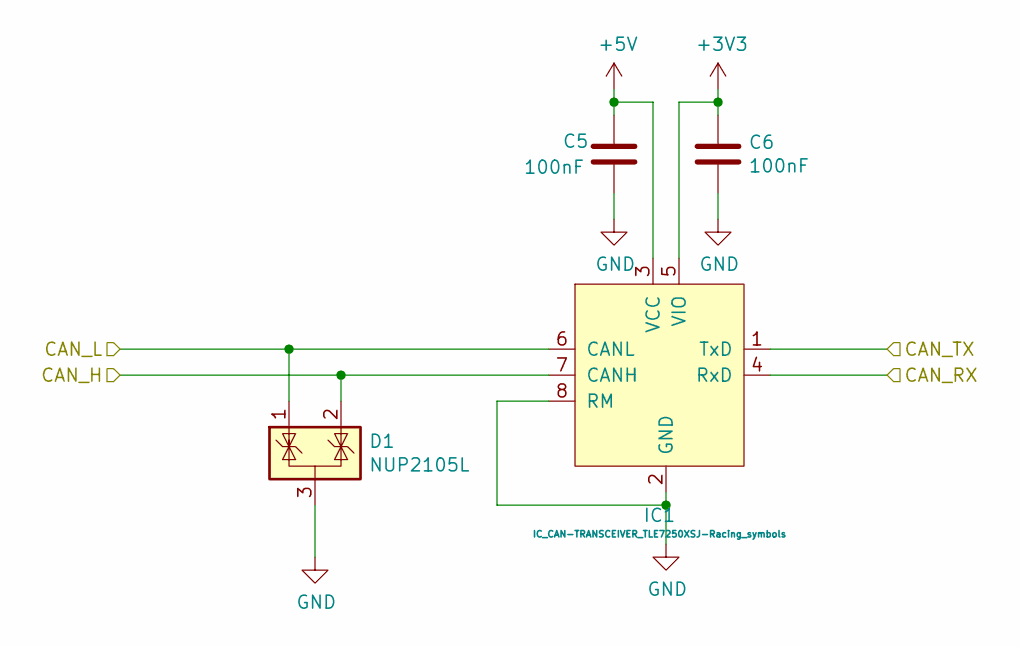
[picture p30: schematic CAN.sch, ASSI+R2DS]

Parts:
C5, C6: 100nF; C_0603_1608Metric
D1: NUP2105L; SOT-23
IC1: IC_CAN-TRANSCEIVER_TLE7250XSJ-Racing_symbols; SOIC-8_3.9x4.9mm_P1.27mm

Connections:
+3V3: C6.1, IC1.5 (VIO); also elsewhere on the board
+5V: C5.1, IC1.3 (VCC); also elsewhere on the board
/CAN/CAN_H: D1.2 (K), IC1.7 (CANH); also elsewhere on the board
/CAN/CAN_L: D1.1 (K), IC1.6 (CANL); also elsewhere on the board
/CAN/CAN_RX: IC1.4 (RxD); also elsewhere on the board
/CAN/CAN_TX: IC1.1 (TxD); also elsewhere on the board
GND: C5.2, C6.2, D1.3 (A), IC1.2 (GND), IC1.8 (RM); also elsewhere on the board

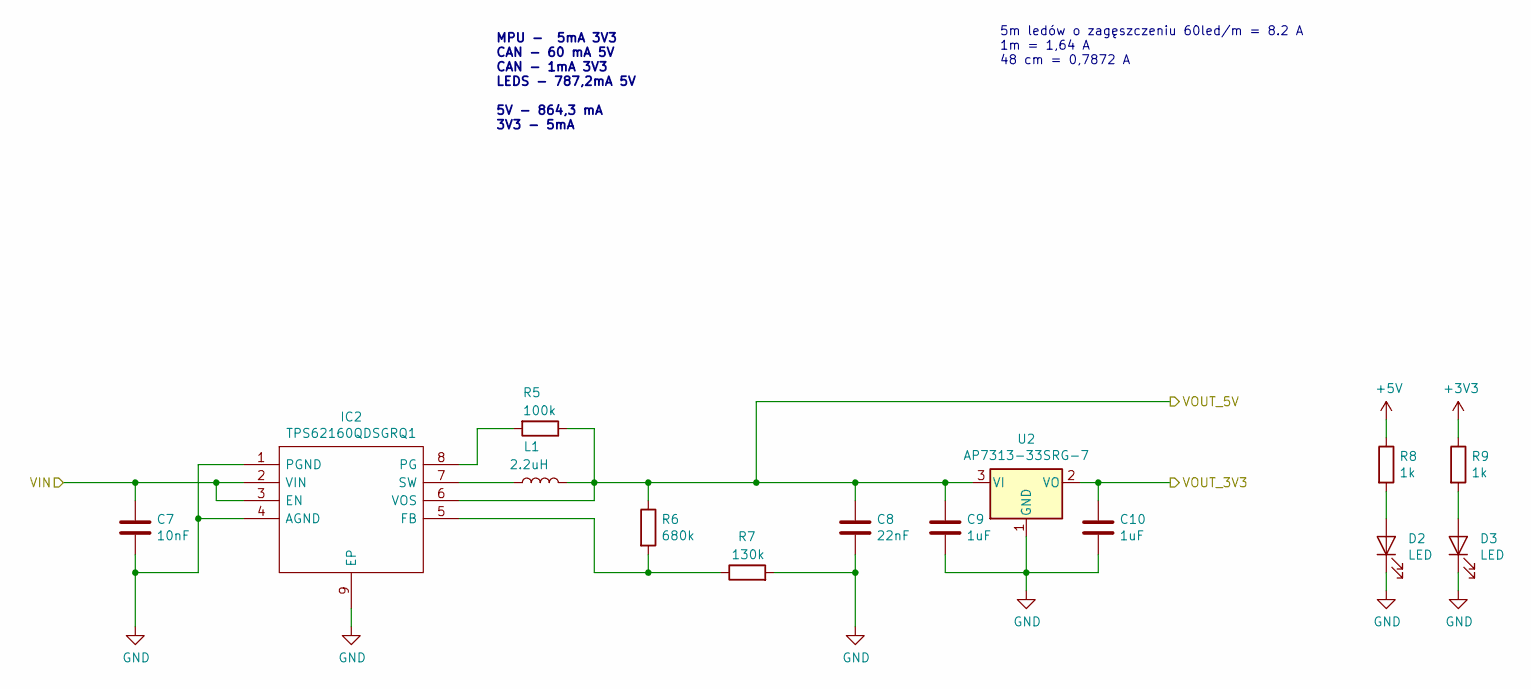
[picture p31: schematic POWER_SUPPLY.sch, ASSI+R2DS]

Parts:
C7: 10nF; C_0603_1608Metric
C8: 22nF; C_0603_1608Metric
C9, C10: 1uF; C_0603_1608Metric
D2, D3: LED; LED_0603_1608Metric
IC2: TPS62160QDSGRQ1; SON50P200X200X80-9N; Mouser Part Number 595-TPS62160QDSGRQ1
L1: 2.2uH; L_0603_1608Metric
R5: 100k; R_0603_1608Metric
R6: 680k; R_0603_1608Metric
R7: 130k; R_0603_1608Metric
R8, R9: 1k; R_0603_1608Metric
U2: AP7313-33SRG-7; SOT-223-3_TabPin2

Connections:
+3V3: C10.1, R9.1, U2.2 (VO); also elsewhere on the board
+5V: C8.1, C9.1, IC2.6 (VOS), L1.2, R5.1, R6.1, R8.1, U2.3 (VI); also elsewhere on the board
/POWER_SUPPLY/VIN: C7.1, IC2.2 (VIN), IC2.3 (EN); also elsewhere on the board
GND: C7.2, C8.2, C9.2, C10.2, D2.1 (K), D3.1 (K), IC2.1 (PGND), IC2.4 (AGND), IC2.9 (EP), R7.2, U2.1 (GND); also elsewhere on the board
unnamed: D2.2 (A), R8.2
unnamed: D3.2 (A), R9.2
unnamed: IC2.5 (FB), R6.2, R7.1
unnamed: IC2.7 (SW), L1.1
unnamed: IC2.8 (PG), R5.2

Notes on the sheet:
5m ledów o zagęszczeniu 60led/m = 8.2 A 1m = 1,64 A 48 cm = 0,7872 A
MPU - 5mA 3V3 CAN - 60 mA 5V CAN - 1mA 3V3 LEDS - 787,2mA 5V 5V - 864,3 mA 3V3 - 5mA

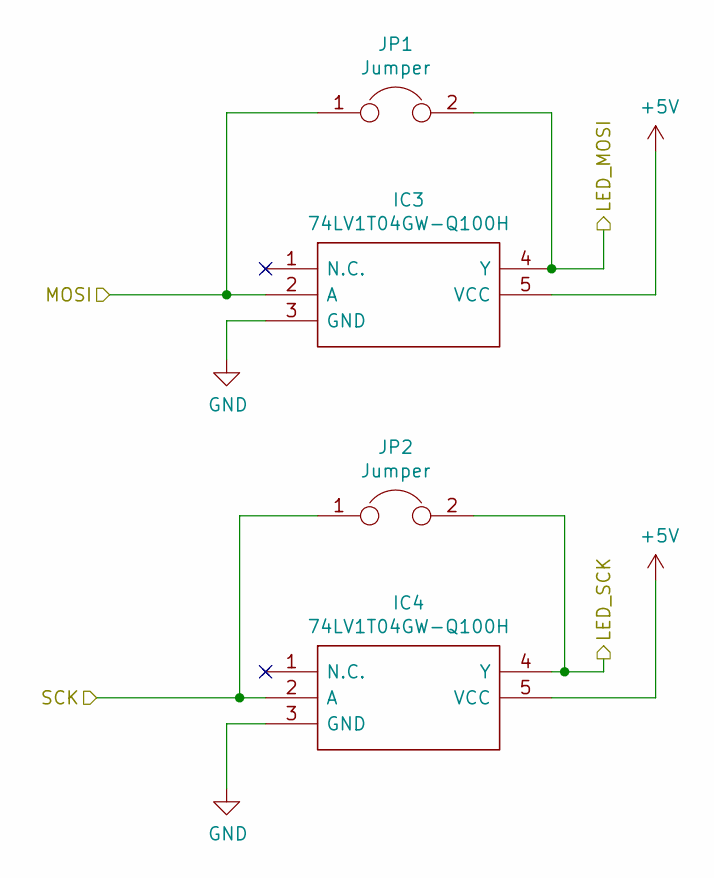
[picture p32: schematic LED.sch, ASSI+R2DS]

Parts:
IC3, IC4: 74LV1T04GW-Q100H; SOT65P212X110-5N; Mouser Part Number 771-74LV1T04GW-Q100H
JP1, JP2: Jumper; PinHeader_1x02_P1.00mm_Vertical

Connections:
+5V: IC3.5 (VCC), IC4.5 (VCC); also elsewhere on the board
/LED/LED_MOSI: IC3.4 (Y), JP1.2; also elsewhere on the board
/LED/LED_SCK: IC4.4 (Y), JP2.2; also elsewhere on the board
/LED/MOSI: IC3.2 (A), JP1.1; also elsewhere on the board
/LED/SCK: IC4.2 (A), JP2.1; also elsewhere on the board
GND: IC3.3 (GND), IC4.3 (GND); also elsewhere on the board

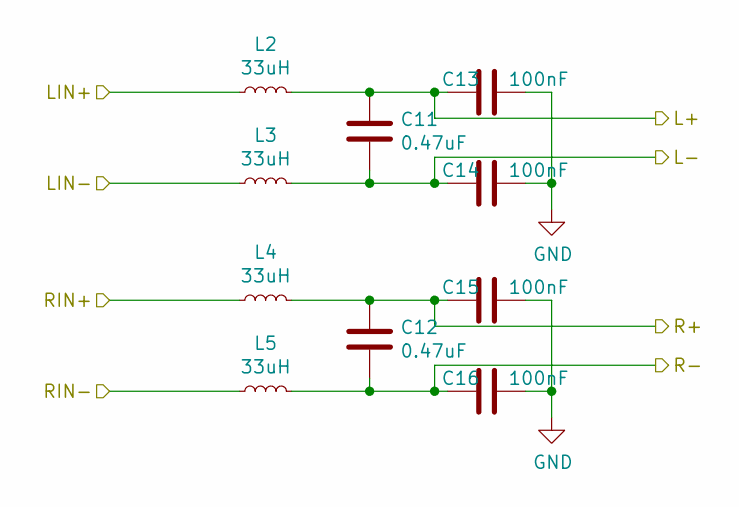
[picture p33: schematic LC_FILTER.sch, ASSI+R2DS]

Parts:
C11, C12: 0.47uF; C_0603_1608Metric
C13, C14, C15, C16: 100nF; C_0603_1608Metric
L2, L3, L4, L5: 33uH; L_0603_1608Metric

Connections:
/LC_FILTER/L+: C11.1, C13.2, L2.2; also elsewhere on the board
/LC_FILTER/L-: C11.2, C14.2, L3.2; also elsewhere on the board
/LC_FILTER/LIN+: L2.1; also elsewhere on the board
/LC_FILTER/LIN-: L3.1; also elsewhere on the board
/LC_FILTER/R+: C12.1, C15.2, L4.2; also elsewhere on the board
/LC_FILTER/R-: C12.2, C16.2, L5.2; also elsewhere on the board
/LC_FILTER/RIN+: L4.1; also elsewhere on the board
/LC_FILTER/RIN-: L5.1; also elsewhere on the board
GND: C13.1, C14.1, C15.1, C16.1; also elsewhere on the board

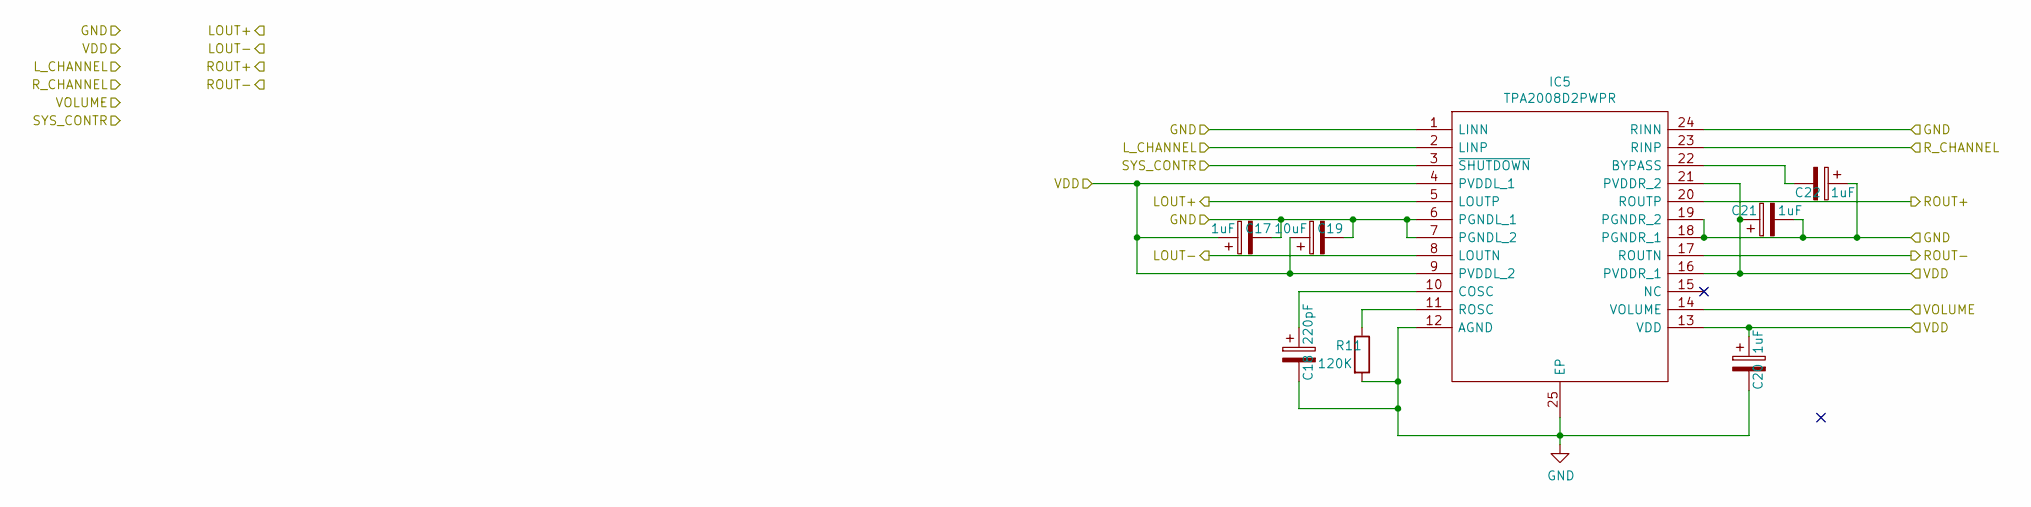
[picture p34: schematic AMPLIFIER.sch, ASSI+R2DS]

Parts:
C17, C20, C21, C22: 1uF; C_0603_1608Metric
C18: 220pF; C_0603_1608Metric
C19: 10uF; C_0603_1608Metric
IC5: TPA2008D2PWPR; SOP65P640X120-25N; Mouser Part Number 595-TPA2008D2PWPR
R11: 120K; R_0603_1608Metric

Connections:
+5V: C17.1, C19.1, C20.1, C21.1, IC5.4 (PVDDL_1), IC5.9 (PVDDL_2), IC5.13 (VDD), IC5.16 (PVDDR_1), IC5.21 (PVDDR_2); also elsewhere on the board
/AMPLIFIER/SYS_CONTR: IC5.3 (~SHUTDOWN)
/LC_FILTER/LIN+: IC5.5 (LOUTP); also elsewhere on the board
/LC_FILTER/LIN-: IC5.8 (LOUTN); also elsewhere on the board
/LC_FILTER/RIN+: IC5.20 (ROUTP); also elsewhere on the board
/LC_FILTER/RIN-: IC5.17 (ROUTN); also elsewhere on the board
/STM32/AMP_L_CHANNEL: IC5.2 (LINP); also elsewhere on the board
/STM32/AMP_R_CHANNEL: IC5.23 (RINP); also elsewhere on the board
/STM32/AMP_VOLUME: IC5.14 (VOLUME); also elsewhere on the board
GND: C17.2, C18.2, C19.2, C20.2, C21.2, C22.1, IC5.1 (LINN), IC5.6 (PGNDL_1), IC5.7 (PGNDL_2), IC5.12 (AGND), IC5.18 (PGNDR_1), IC5.19 (PGNDR_2), IC5.24 (RINN), IC5.25 (EP), R11.2; also elsewhere on the board
unnamed: C18.1, IC5.10 (COSC)
unnamed: C22.2, IC5.22 (BYPASS)
unnamed: IC5.11 (ROSC), R11.1

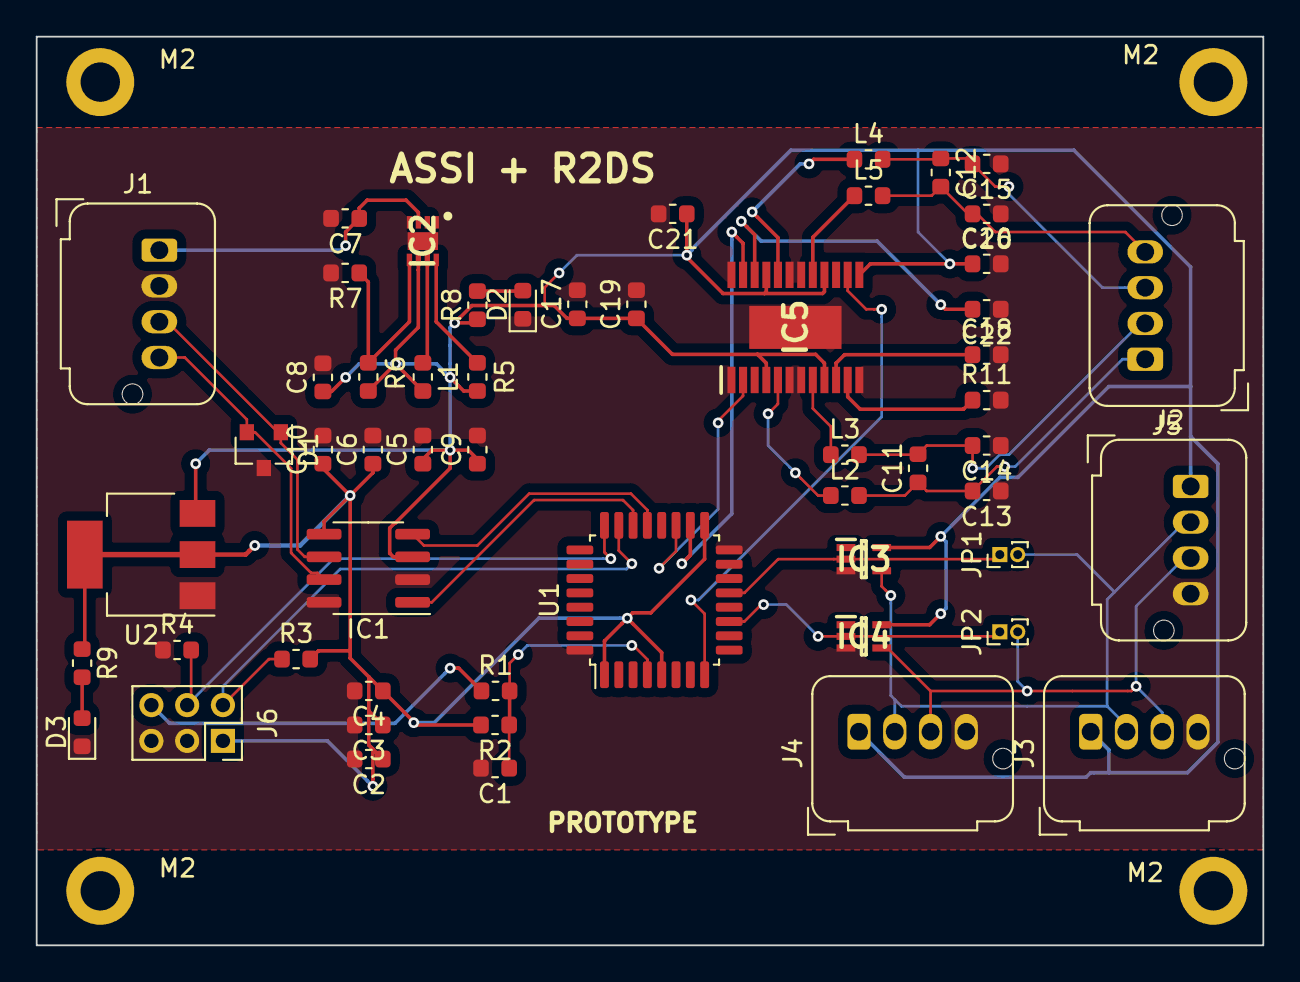
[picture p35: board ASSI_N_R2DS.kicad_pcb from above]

Board: 2 copper layers, 68.6 x 50.8 mm, 59 parts (0 on the bottom side), 35 nets.

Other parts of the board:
M2, M2#2, M2#3, M2#4: MountingHole_2.2mm_M2_ISO14580_Pad

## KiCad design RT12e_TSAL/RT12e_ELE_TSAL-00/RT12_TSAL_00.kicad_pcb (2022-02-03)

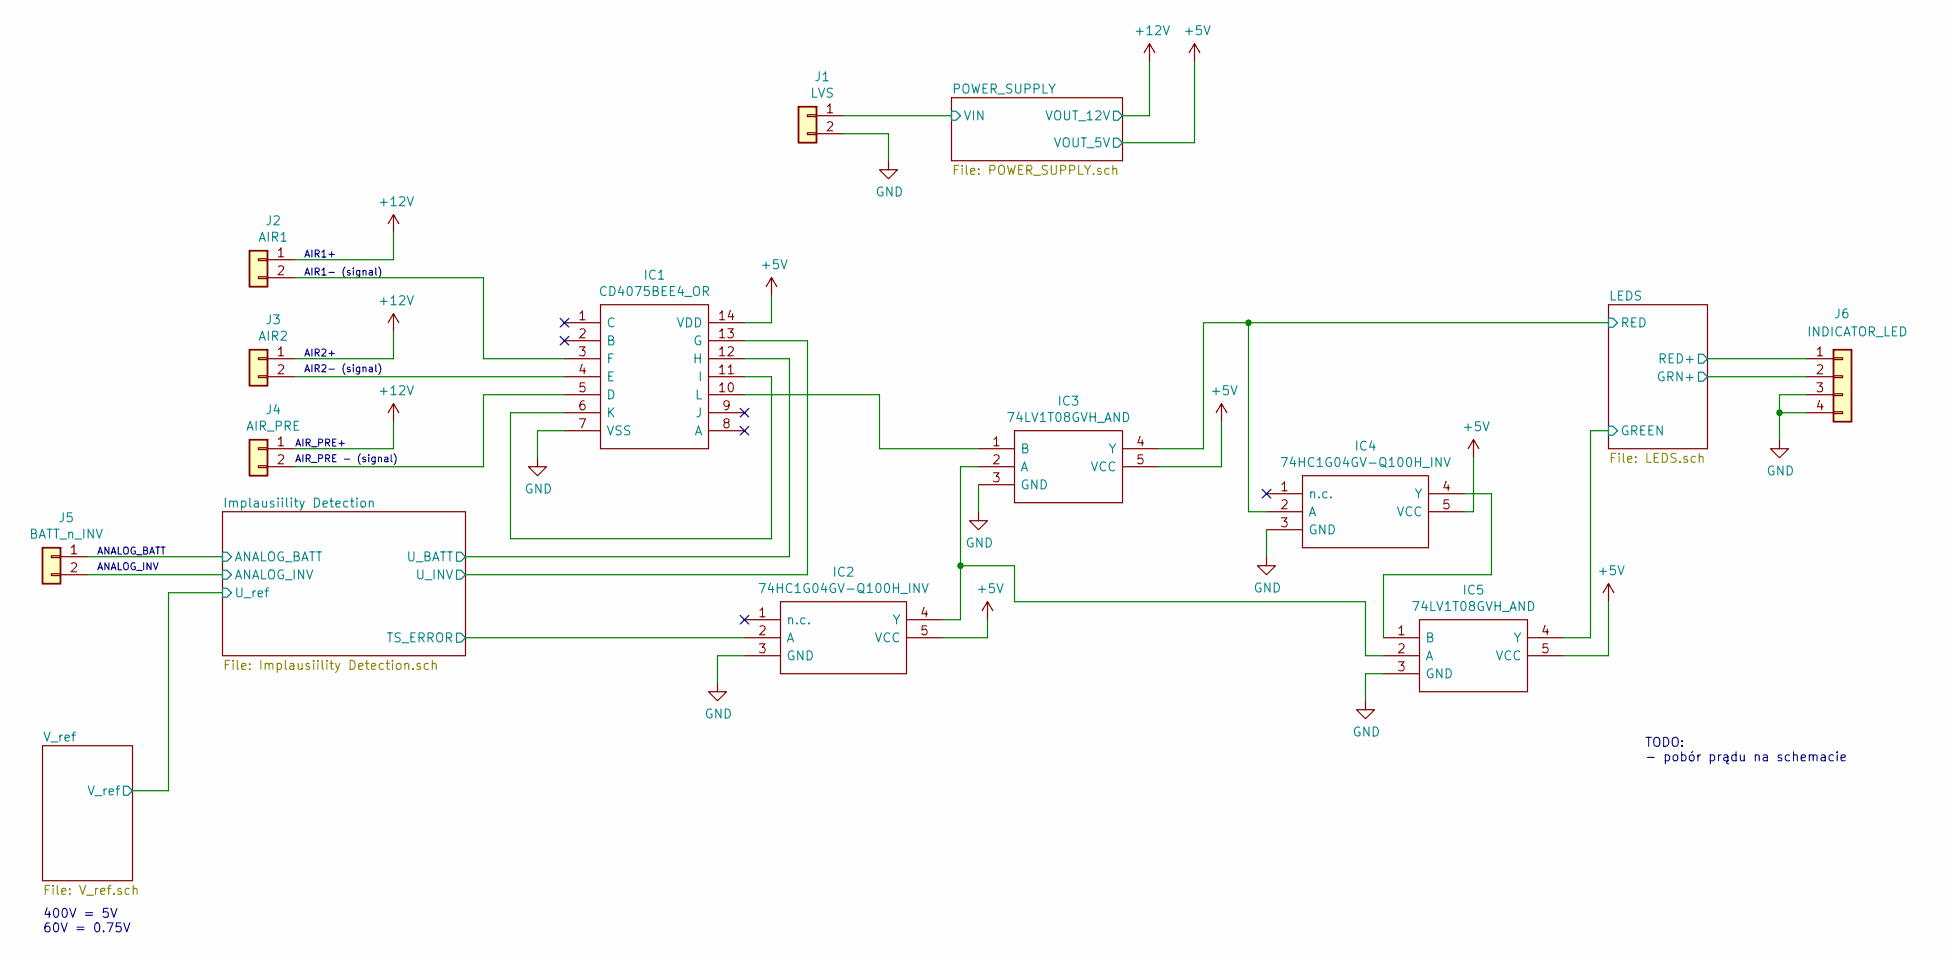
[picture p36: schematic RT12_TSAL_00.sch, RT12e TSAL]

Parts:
IC1: CD4075BEE4_OR; DIP794W53P254L1930H508Q14N; Mouser Part Number 595-CD4075BEE4
IC2, IC4: 74HC1G04GV-Q100H_INV; SOT95P275X110-5N; Mouser Part Number 771-74HC1G04GV-Q100H
IC3, IC5: 74LV1T08GVH_AND; SOT95P275X110-5N; Mouser Part Number 771-74LV1T08GVH
J1: LVS; Molex_PicoBlade_53047-0210_1x02_P1.25mm_Vertical
J2: AIR1; Molex_PicoBlade_53047-0210_1x02_P1.25mm_Vertical
J3: AIR2; Molex_PicoBlade_53047-0210_1x02_P1.25mm_Vertical
J4: AIR_PRE; Molex_PicoBlade_53047-0210_1x02_P1.25mm_Vertical
J5: BATT_n_INV; Molex_PicoBlade_53047-0210_1x02_P1.25mm_Vertical
J6: INDICATOR_LED; Molex_SPOX_5267-04A_1x04_P2.50mm_Vertical

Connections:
+5V: IC1.14 (VDD), IC2.5 (VCC), IC3.5 (VCC), IC4.5 (VCC), IC5.5 (VCC); also elsewhere on the board
+12V: J1.1, J2.1, J3.1, J4.1; also elsewhere on the board
/Implausiility Detection/ANALOG_BATT: J5.1; also elsewhere on the board
/Implausiility Detection/ANALOG_INV: J5.2; also elsewhere on the board
/Implausiility Detection/TS_ERROR: IC2.2 (A); also elsewhere on the board
/Implausiility Detection/U_BATT: IC1.12 (H); also elsewhere on the board
/Implausiility Detection/U_INV: IC1.13 (G); also elsewhere on the board
/LEDS/GREEN: IC5.4 (Y); also elsewhere on the board
/LEDS/GRN+: J6.2; also elsewhere on the board
/LEDS/RED: IC3.4 (Y), IC4.2 (A); also elsewhere on the board
/LEDS/RED+: J6.1; also elsewhere on the board
GND: IC1.7 (VSS), IC2.3 (GND), IC3.3 (GND), IC4.3 (GND), IC5.3 (GND), J1.2, J6.3, J6.4; also elsewhere on the board
unnamed: IC1.10 (L), IC3.1 (B)
unnamed: IC1.6 (K), IC1.11 (I)
unnamed: IC2.4 (Y), IC3.2 (A), IC5.2 (A)
unnamed: IC4.4 (Y), IC5.1 (B)

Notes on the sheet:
AIR1- (signal)
AIR1+
AIR2- (signal)
AIR2+
AIR_PRE - (signal)
AIR_PRE+
ANALOG_INV
ANALOG_BATT
400V = 5V 60V = 0.75V
TODO: - pobór prądu na schemacie

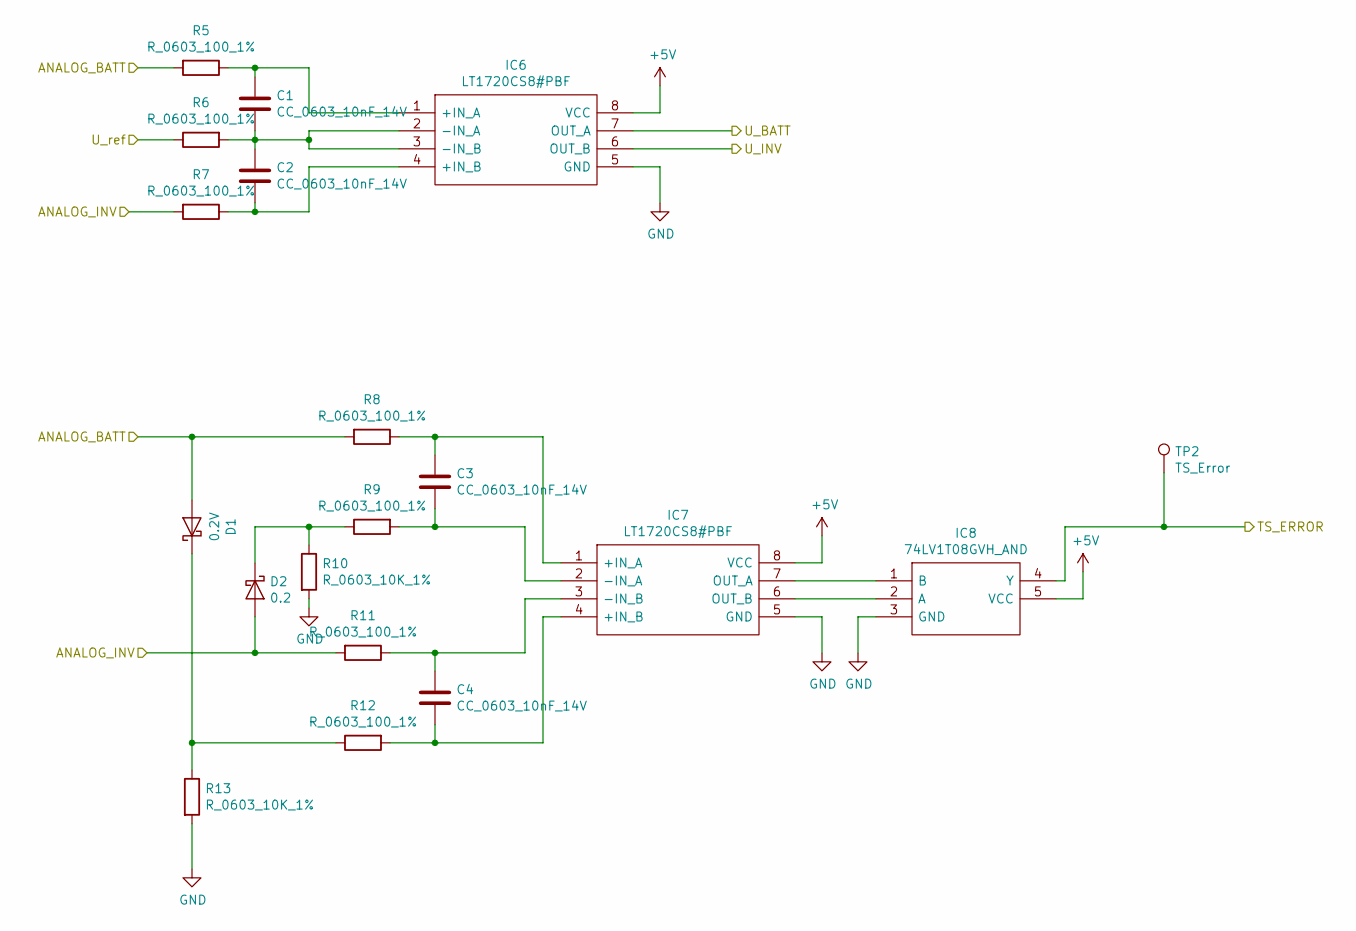
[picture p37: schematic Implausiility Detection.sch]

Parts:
C1, C2: CC_0603_10nF_14V; C_0603_1608Metric_Pad1.05x0.95mm_HandSolder
C3, C4: CC_0603_10nF_14V; C_0603_1608Metric
D1: 0.2V; D_0603_1608Metric_Pad1.05x0.95mm_HandSolder
D2: 0.2; D_0603_1608Metric_Pad1.05x0.95mm_HandSolder
IC6, IC7: LT1720CS8#PBF; SOIC127P599X175-8N; Mouser Part Number 584-LT1720CS8#PBF
IC8: 74LV1T08GVH_AND; SOT95P275X110-5N; Mouser Part Number 771-74LV1T08GVH
R5, R6, R7, R11, R12: R_0603_100_1%; R_0603_1608Metric_Pad1.05x0.95mm_HandSolder
R8, R9: R_0603_100_1%; R_0603_1608Metric
R10: R_0603_10K_1%; R_0603_1608Metric
R13: R_0603_10K_1%; R_0603_1608Metric_Pad1.05x0.95mm_HandSolder
TP2: TS_Error; TestPoint_THTPad_2.0x2.0mm_Drill1.0mm

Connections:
+5V: IC6.8 (VCC), IC7.8 (VCC), IC8.5 (VCC); also elsewhere on the board
/Implausiility Detection/ANALOG_BATT: D1.2 (A), R5.2, R8.2; also elsewhere on the board
/Implausiility Detection/ANALOG_INV: D2.2 (A), R7.2, R11.2; also elsewhere on the board
/Implausiility Detection/TS_ERROR: IC8.4 (Y), TP2.1; also elsewhere on the board
/Implausiility Detection/U_BATT: IC6.7 (OUT_A); also elsewhere on the board
/Implausiility Detection/U_INV: IC6.6 (OUT_B); also elsewhere on the board
/Implausiility Detection/U_ref: R6.1; also elsewhere on the board
GND: IC6.5 (GND), IC7.5 (GND), IC8.3 (GND), R10.2, R13.2; also elsewhere on the board
unnamed: C1.1, IC6.1 (+IN_A), R5.1
unnamed: C1.2, C2.1, IC6.2 (-IN_A), IC6.3 (-IN_B), R6.2
unnamed: C2.2, IC6.4 (+IN_B), R7.1
unnamed: C3.1, IC7.1 (+IN_A), R8.1
unnamed: C3.2, IC7.2 (-IN_A), R9.2
unnamed: C4.1, IC7.3 (-IN_B), R11.1
unnamed: C4.2, IC7.4 (+IN_B), R12.2
unnamed: D1.1 (K), R12.1, R13.1
unnamed: D2.1 (K), R9.1, R10.1
unnamed: IC7.6 (OUT_B), IC8.2 (A)
unnamed: IC7.7 (OUT_A), IC8.1 (B)

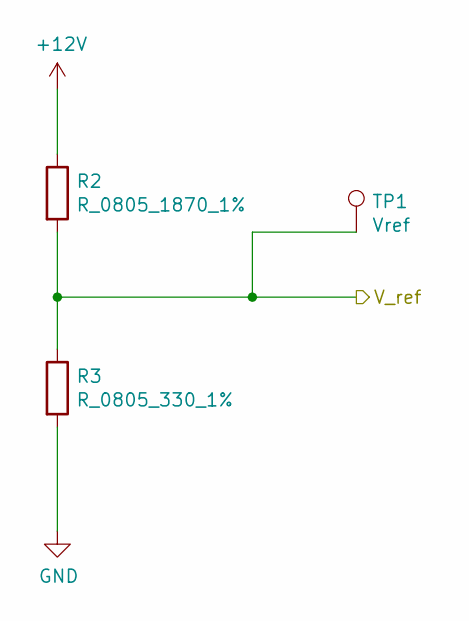
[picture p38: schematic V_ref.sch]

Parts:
R2: R_0805_1870_1%; R_0805_2012Metric
R3: R_0805_330_1%; R_0805_2012Metric_Pad1.15x1.40mm_HandSolder
TP1: Vref; TestPoint_THTPad_2.0x2.0mm_Drill1.0mm

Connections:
+12V: R2.1; also elsewhere on the board
/Implausiility Detection/U_ref: R2.2, R3.1, TP1.1; also elsewhere on the board
unnamed 43: R3.2; also elsewhere on the board


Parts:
C5, C6: CC_0603_100nF_14V; C_0603_1608Metric
C7: CC_0603_1uF_14V; C_0603_1608Metric
D3: D_LED_0603_GREEN_20mA; D_0603_1608Metric_Pad1.05x0.95mm_HandSolder
D4: D_LED_0603_RED_20mA; D_0603_1608Metric_Pad1.05x0.95mm_HandSolder
Q1, Q2, Q3: BSS123; SOT-23
Q4: BSS84; SOT-23
R14, R20: R_0603_2K2_5%; R_0603_1608Metric_Pad1.05x0.95mm_HandSolder
R15, R16: R_0603_22K_5%; R_0603_1608Metric_Pad1.05x0.95mm_HandSolder
R17: R_0603_47_5%; R_0603_1608Metric_Pad1.05x0.95mm_HandSolder
R18: R_0603_220K_5%; R_0603_1608Metric_Pad1.05x0.95mm_HandSolder
R19: R_0603_10K_5%; R_0603_1608Metric_Pad1.05x0.95mm_HandSolder
TP3: RED; TestPoint_THTPad_2.0x2.0mm_Drill1.0mm
TP4: GRN; TestPoint_THTPad_2.0x2.0mm_Drill1.0mm
U1: NE555; NE555DR

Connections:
+12V: C5.1, D3.2 (A), Q4.3 (D), R15.1, R16.1, R19.1, U1.8 (VCC); also elsewhere on the board
/LEDS/GREEN: Q1.1 (G), TP4.1; also elsewhere on the board
/LEDS/GRN+: Q1.2 (S); also elsewhere on the board
/LEDS/RED: Q2.1 (G), TP3.1; also elsewhere on the board
/LEDS/RED+: D4.2 (A), Q4.2 (S); also elsewhere on the board
GND: C5.2, C6.2, C7.2, Q2.2 (S), Q3.2 (S), R20.1, U1.1 (GND); also elsewhere on the board
unnamed: C6.1, U1.5 (CV)
unnamed: C7.1, R18.2, U1.2 (TR), U1.6 (THR)
unnamed: D3.1 (K), R14.1
unnamed: D4.1 (K), R20.2
unnamed: Q1.3 (D), R14.2
unnamed: Q2.3 (D), R15.2, U1.4 (R)
unnamed: Q3.1 (G), R17.1
unnamed: Q3.3 (D), Q4.1 (G), R19.2
unnamed: R16.2, R18.1, U1.7 (DIS)
unnamed: R17.2, U1.3 (Q)

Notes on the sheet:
GREEN INDICATOR
RED INDICATOR


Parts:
D5: VCC; LED_0603_1608Metric
IC9: ZSR500GTA; SOT230P700X180-4N; Mouser Part Number 522-ZSR500GTA
R1: R_0603_1K_5%; R_0603_1608Metric_Pad1.05x0.95mm_HandSolder

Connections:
+5V: IC9.1 (OUT), R1.1; also elsewhere on the board
+12V: IC9.3 (IN); also elsewhere on the board
GND: D5.1 (K), IC9.2 (GND_1), IC9.4 (GND_2); also elsewhere on the board
unnamed: D5.2 (A), R1.2

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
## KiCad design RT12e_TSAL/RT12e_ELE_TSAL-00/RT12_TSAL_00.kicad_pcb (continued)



Board: 2 copper layers, 52.6 x 35.6 mm, 59 parts (15 on the bottom side), 46 nets.

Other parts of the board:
C8, C9, C10: 100n; C_0603_1608Metric_Pad1.05x0.95mm_HandSolder
R4: R_0805_575_1%; R_0805_2012Metric_Pad1.15x1.40mm_HandSolder

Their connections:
GND: R4.2; also elsewhere on the board
unnamed 43: R4.1; also elsewhere on the board

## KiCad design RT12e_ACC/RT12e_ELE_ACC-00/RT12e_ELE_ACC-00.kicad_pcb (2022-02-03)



Board: 2 copper layers, 31.0 x 20.0 mm, 33 parts (5 on the bottom side), 23 nets.

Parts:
C1, C12: 10uF; C_1206_3216Metric
C2, C3, C5, C6, C7, C8, C9, C11, C13: 100nF; C_0603_1608Metric
C4: 1uF; C_1206_3216Metric
C10: 0.47uF; C_1206_3216Metric
D1: D; D_1206_3216Metric
D2, D3: D; C_0603_1608Metric
D4: NUP2105L; SOT-23
J1: 5V_CAN; PinHeader_1x04_P2.00mm_Vertical
J2: SWD; PinHeader_2x03_P2.00mm_Vertical
L1, L2, L3: L; L_0805_2012Metric
R1: 270; R_0603_1608Metric
R2: 150; R_0603_1608Metric
R3: 100; R_0603_1608Metric
R4, R5, R6: 10K; R_0603_1608Metric
Ref**: Val**; PWR_logo_11x2,5
U1: LM1085-3.3; SOT-23
U2: STM32F042K6Tx; TQFP-32_7x7mm_P0.8mm
U3: IAM-20680; LGA-16_3x3mm_P0.5mm_LayoutBorder3x5y
U4: SN65HVD230; SOIC-8_3.9x4.9mm_P1.27mm

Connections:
+3V3: C3.1, C4.1, C12.1, C13.1, L2.1, L3.2, R2.1, U1.2, U4.3
+5V: C2.1, L1.2, R1.1, U1.3
/CAN+: D4.2, J1.1, U4.7
/CAN-: D4.1, J1.2, U4.6
/CAN/CAN_RX: U2.21, U4.4
/CAN/CAN_TX: U2.22, U4.1
/IAM-20680/ACC_V+: C9.1, C11.1, L3.1, U3.1, U3.16
/IAM-20680/CS: U2.10, U3.5
/IAM-20680/REGOUT: C10.1, U3.14
/IAM-20680/SDI: U2.13, U3.3
/IAM-20680/SDO: U2.12, U3.4
/IAM-20680/SPC: U2.11, U3.2
/STM32/DI_IAM_INT: U2.31, U3.6
/STM32/RESET: J2.6, R3.2
/STM32/STM_RESET: C8.1, R3.1, R4.2, U2.4
/STM32/STM_V+: C5.1, C6.1, C7.1, J2.1, L2.2, R4.1, R5.1, U2.1, U2.5, U2.17
/STM32/SWCLK: J2.4, R6.1, U2.24
/SWD_connect.sch/SDWIO: J2.2, R5.2, U2.23
/VIN: D1.2, J1.4
GND: C1.2, C2.2, C3.2, C4.2, C5.2, C6.2, C7.2, C8.2, C9.2, C10.2, C11.2, C12.2, C13.2, D2.1, D3.1, D4.3, J1.3, J2.3, J2.5, R6.2, U1.1, U2.2, U2.3, U2.6, U2.7, U2.8, U2.9, U2.14, U2.15, U2.16, U2.18, U2.19, U2.20, U2.26, U2.27, U2.28, U2.29, U2.30, U2.32, U3.8, U3.9, U3.10, U3.11, U3.12, U3.13, U3.15, U4.2, U4.8
unnamed: C1.1, D1.1, L1.1
unnamed: D2.2, R1.2
unnamed: D3.2, R2.2
